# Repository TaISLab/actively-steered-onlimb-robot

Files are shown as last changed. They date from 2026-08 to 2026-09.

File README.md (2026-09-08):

# Actively Steered Open On-Limb Robot 

On-limb robot designed to move along compliant cylindrical surfaces, such as human limbs or pipes. The platform integrates active steering, proprioceptive sensing, embedded control electronics, and compliant mechanical adaptation for locomotion on variable-diameter surfaces.

This repository accompanies the paper:

> Tobar-Subía-Contento, L.M.; Valenzuela, J.; Mandow, A.; Gómez-de-Gabriel, J.M. **"Actively Steered Open On-Limb Robot with Alignment Control and Online Diameter Estimation."** *Electronics* **2026**, *15*(17), 4028. https://doi.org/10.3390/electronics15174028

The main contribution is an integrated open on-limb robotic platform with active steering for real-time locomotion and alignment control. A generalized kinematic framework based on the complete Jacobian of the roller centers provides a geometric alignment variable for closed-loop steering correction and enables coordinate-independent online estimation of the supporting surface diameter from proprioceptive measurements.

Experiments on variable-diameter surfaces demonstrate the robot's ability to maintain centered longitudinal locomotion, handle non-symmetric link deflections, and estimate the local diameter online.

## Repository Contents

The repository is organized into two main sections:

```text
repository/
├── CAD/
├── electronics/
├── ControlSoftware/
├── MICIU+Cofinanciado+AEI.jpg
├── README.md
├── CITATION.cff
└── LICENSE
```

## Mechanical Design

The `mechanical/STL/` directory contains the mechanical components required to fabricate the robot structure using **additive manufacturing (3D printing)**.

The structural components of the prototype reported in the associated publication were fabricated using **polylactic acid (PLA)**.

### 3D Printing

Printing parameters may need to be adjusted depending on the printer, material, nozzle, layer height, and desired mechanical properties.

Users should verify dimensional tolerances and mechanical compatibility before final assembly.

## Electronics

The `electronics/` directory contains the electronic design files associated with the wearable robot prototype.

The electronics were designed using **KiCad** and the directory includes the complete project required to inspect the electrical schematic and PCB layout:

```text
electronics/
├── proyecto_robot_limbot.kicad_pro
├── proyecto_robot_limbot.kicad_sch
└── proyecto_robot_limbot.kicad_pcb
```

The files correspond to:

* **`.kicad_pro`** — KiCad project configuration.
* **`.kicad_sch`** — electronic schematic of the system.
* **`.kicad_pcb`** — printed circuit board (PCB) layout.

The project can be opened directly in **KiCad** using the `.kicad_pro` file.

Temporary files, local configuration files, autosaves, and backup directories generated automatically by KiCad are not included in the repository.

The electronic design files are provided to support reproduction, inspection, and further development of the hardware used in the research prototype.

# Control Software

This folder contains the software used for the control and experimental operation of the actively-steered on-limb robot.

The embedded control code was implemented for the ESP32-based controller and includes motor position control, servo control, sensor acquisition, signal filtering, serial communication, and experimental data transmission.

```text
ControlSoftware/
├── actively-steered-onlimb-robot.ino
├── robot_control_interface.py
```

## Citation

If you use or adapt the files, mechanical designs, or electronic designs contained in this repository for academic or research purposes, please cite the associated publication (see reference above) and, when appropriate, this repository.

GitHub users can use the **“Cite this repository”** option, or refer directly to the `CITATION.cff` file included in this repository, which contains the complete bibliographic metadata for both the article and the repository.

## Funding

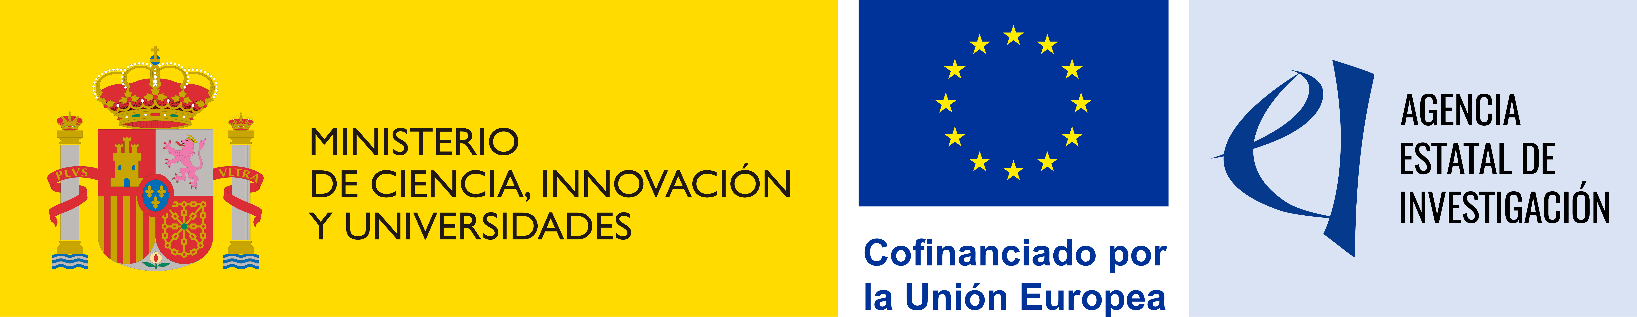
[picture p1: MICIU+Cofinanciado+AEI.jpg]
MICIU/AEI logo


This work is part of project PID2021-127221OB-I00 (CONCERTO — Control Colaborativo para Interacción física Empática entre RoboT y humanO), funded by MICIU/AEI/10.13039/501100011033/FEDER, UE.

## Acknowledgment

This repository accompanies academic research on wearable robotic systems and is provided to facilitate reproducibility and further research in the field.

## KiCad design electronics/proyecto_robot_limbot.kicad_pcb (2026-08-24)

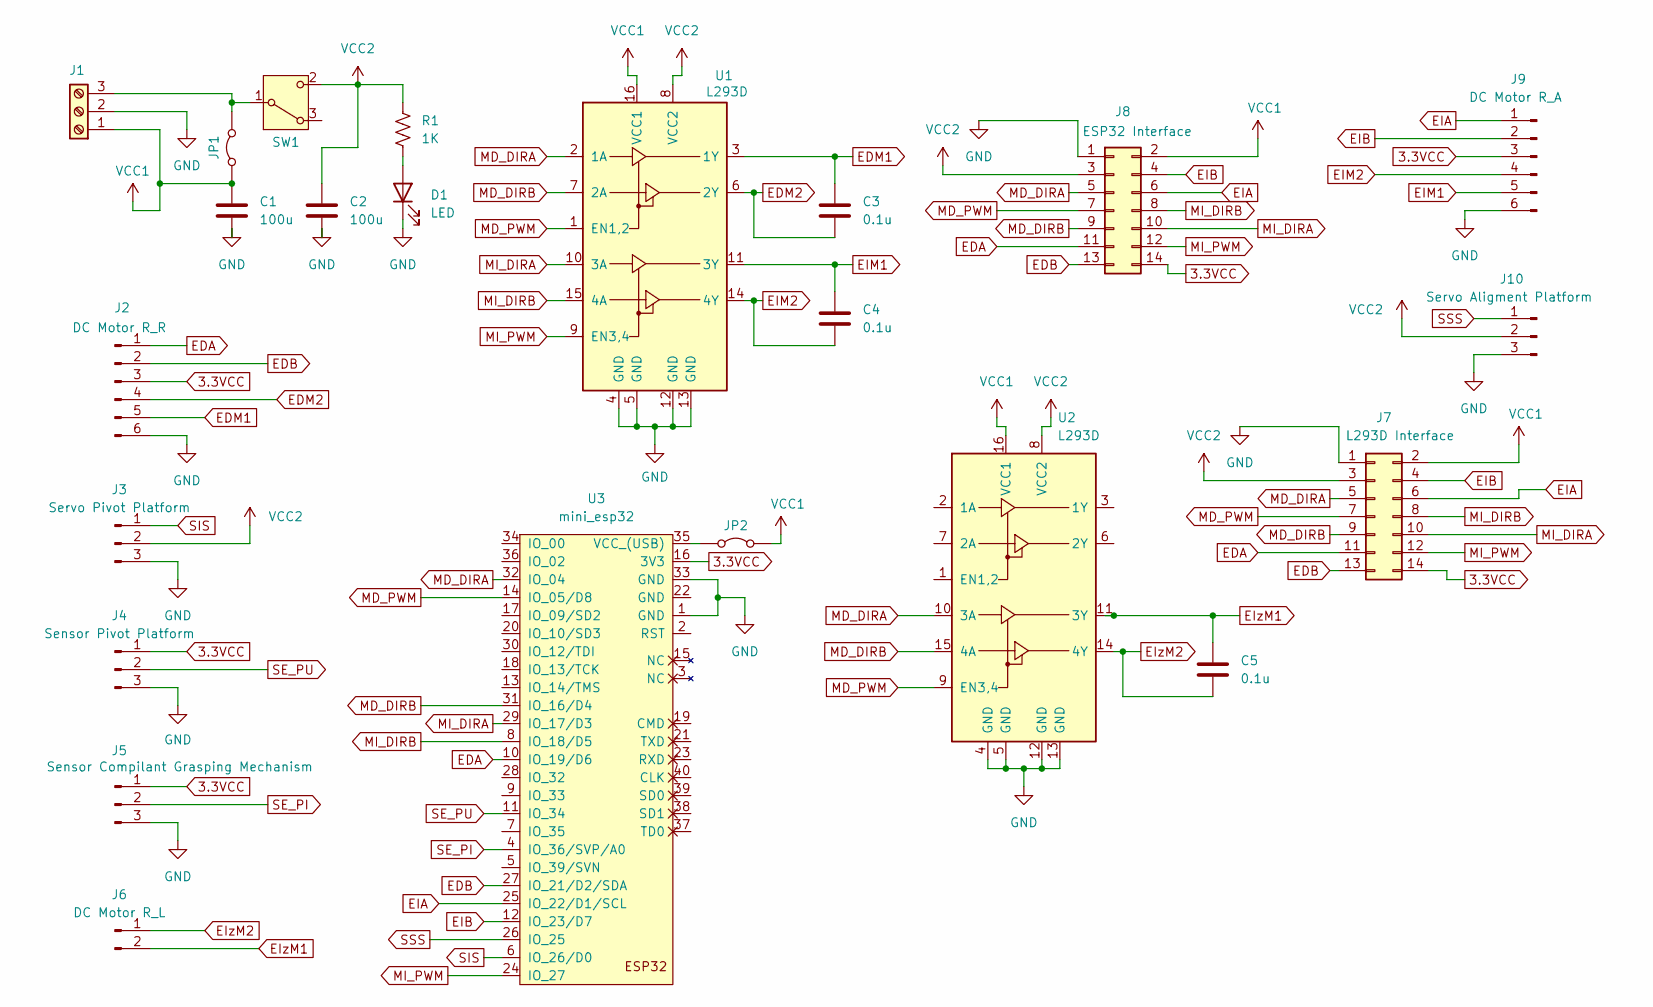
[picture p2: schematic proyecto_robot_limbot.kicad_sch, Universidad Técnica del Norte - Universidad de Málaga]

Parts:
C1, C2: 100u; C_Disc_D3.4mm_W2.1mm_P2.50mm
C3, C4, C5: 0.1u; C_Disc_D3.4mm_W2.1mm_P2.50mm
D1: LED; LED_D3.0mm_Clear
J1: TerminalBlock_MetzConnect_Type086_RT03403HBLC_1x03_P3.81mm_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
J2: DC Motor R_R; Molex_Micro-Latch_53254-0670_1x06_P2.00mm_Horizontal
J3: Servo Pivot Platform; Molex_Micro-Latch_53254-0370_1x03_P2.00mm_Horizontal
J4: Sensor Pivot Platform; Molex_Micro-Latch_53254-0370_1x03_P2.00mm_Horizontal
J5: Sensor Compilant Grasping Mechanism; Molex_Micro-Latch_53254-0370_1x03_P2.00mm_Horizontal
J6: DC Motor R_L; Molex_Micro-Latch_53254-0270_1x02_P2.00mm_Horizontal
J7: L293D Interface; PinSocket_2x07_P2.54mm_Vertical
J8: ESP32 Interface; PinHeader_2x07_P2.54mm_Vertical
J9: DC Motor R_A; Molex_Micro-Latch_53254-0670_1x06_P2.00mm_Horizontal
J10: Servo Aligment Platform; Molex_Micro-Latch_53254-0370_1x03_P2.00mm_Horizontal
JP1, JP2: TestPoint_2Pads_Pitch2.54mm_Drill0.8mm
R1: 1K; R_Axial_DIN0204_L3.6mm_D1.6mm_P5.08mm_Horizontal
SW1: SW_Slide-03_Wuerth-WS-SLTV_10x2.5x6.4_P2.54mm
U1, U2: L293D; DIP-16_W7.62mm_Socket_LongPads
U3: mini_esp32; ESP32_mini

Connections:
3.3VCC: J2.3, J4.1, J5.1, J7.14, J8.14, J9.3, U3.16 (3V3)
EDA: J2.1, J7.11, J8.11, U3.10 (IO_19/D6)
EDB: J2.2, J7.13, J8.13, U3.27 (IO_21/D2/SDA)
EDM1: C3.2, J2.5, U1.3 (1Y)
EDM2: C3.1, J2.4, U1.6 (2Y)
EIA: J7.6, J8.6, J9.1, U3.25 (IO_22/D1/SCL)
EIB: J7.4, J8.4, J9.2, U3.12 (IO_23/D7)
EIM1: C4.1, J9.5, U1.11 (3Y)
EIM2: C4.2, J9.4, U1.14 (4Y)
EIzM1: C5.2, J6.2, U2.11 (3Y)
EIzM2: C5.1, J6.1, U2.14 (4Y)
GND: C1.1, C2.1, D1.1 (K), J1.2, J2.6, J3.3, J4.3, J5.3, J7.1, J8.1, J9.6, J10.3, U1.4 (GND), U1.5 (GND), U1.12 (GND), U1.13 (GND), U2.4 (GND), U2.5 (GND), U2.12 (GND), U2.13 (GND), U3.1 (GND), U3.33 (GND)
MD_DIRA: J7.5, J8.5, U1.2 (1A), U2.10 (3A), U3.32 (IO_04)
MD_DIRB: J7.9, J8.9, U1.7 (2A), U2.15 (4A), U3.31 (IO_16/D4)
MD_PWM: J7.7, J8.7, U1.1 (EN1,2), U2.9 (EN3,4), U3.14 (IO_05/D8)
MI_DIRA: J7.10, J8.10, U1.10 (3A), U3.29 (IO_17/D3)
MI_DIRB: J7.8, J8.8, U1.15 (4A), U3.8 (IO_18/D5)
MI_PWM: J7.12, J8.12, U1.9 (EN3,4), U3.24 (IO_27)
unnamed: D1.2 (A), R1.1
unnamed: J1.3, JP1.2 (B), SW1.1 (B)
unnamed: JP2.1 (A), U3.35 (VCC_(USB))
SE_PI: J5.2, U3.4 (IO_36/SVP/A0)
SE_PU: J4.2, U3.11 (IO_34)
SIS: J3.1, U3.6 (IO_26/D0)
SSS: J10.1, U3.26 (IO_25)
VCC1: C1.2, J1.1, J7.2, J8.2, JP1.1 (A), JP2.2 (B), U1.16 (VCC1), U2.16 (VCC1)
VCC2: C2.2, J3.2, J7.3, J8.3, J10.2, R1.2, SW1.2 (C), U1.8 (VCC2), U2.8 (VCC2)

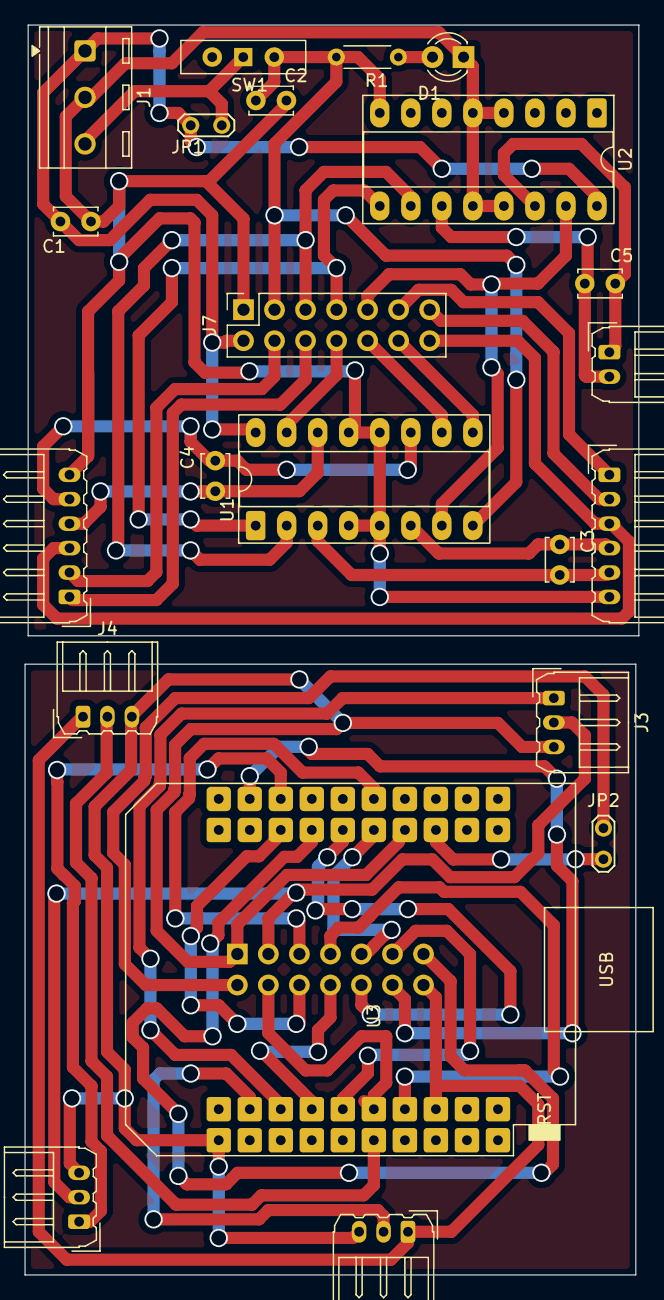
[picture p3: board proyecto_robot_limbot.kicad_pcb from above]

Board: 2 copper layers, 50.3 x 102.3 mm, 23 parts (1 on the bottom side), 27 nets.

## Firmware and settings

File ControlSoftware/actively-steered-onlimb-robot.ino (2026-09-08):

#include <ESP32Encoder.h>
#include <PID_v1.h>
#include <ESP32Servo.h>
/// Placa ESP32 NodeMCU-32s
// ============================
// CONFIGURACIÓN DE PINES
// ============================
#define MD1_DIRA 4      // Motor 1 dirección A
#define MD1_DIRB 16     // Motor 1 dirección B
#define MD1_PWM  5      // Motor 1 PWM
#define E1A 19          // Encoder 1 canal A
#define E1B 21          // Encoder 1 canal B

#define MD2_DIRA 17     // Motor 2 dirección A
#define MD2_DIRB 18     // Motor 2 dirección B
#define MD2_PWM  27     // Motor 2 PWM
#define E2A 22          // Encoder 2 canal A
#define E2B 23          // Encoder 2 canal B

#define SERVO_SSS 26    // Servo SSS
#define SERVO_SIS 25    // Servo SIS
#define SE_PI 36        // Potenciómetro PI (rho)
#define SE_PU 34        // Potenciómetro PU (theta)

long posicionEncoder1 = 0;
long posicionEncoder2 = 0;

// ============================
// OBJETOS Y VARIABLES
// ============================
Servo sss, sis;  // Objetos para servomotores
ESP32Encoder encoderMotor1, encoderMotor2;  // Encoders para motores

// Variables PID para control de posición
double posicionActual1 = 0, salidaPID1 = 0, posicionDeseada1 = 0;
double posicionActual2 = 0, salidaPID2 = 0, posicionDeseada2 = 0;
PID controladorPID1(&posicionActual1, &salidaPID1, &posicionDeseada1, 40.0, 5.0, 0.0, DIRECT);
PID controladorPID2(&posicionActual2, &salidaPID2, &posicionDeseada2, 40.0, 5.0, 0.0, DIRECT);

// Control PI para compensación del servo SIS
double r_input = 0, r_setpoint = 0, r_output = 90;
double Kp_sis = 5, Ki_sis = 0.5;
PID controladorPISIS(&r_input, &r_output, &r_setpoint, Kp_sis, Ki_sis, 0.0, DIRECT);

// Variables para filtro EMA (Exponential Moving Average)
#define ALPHA 0.5        // Factor de suavizado (0.1-0.5)
float filtered_PU = 0, filtered_PI = 0;
bool primera_lectura = true;

// Variables de comunicación con Python
bool enviarDatos = false;      // Controla envío de datos CSV
unsigned long tiempoInicio = 0; // Para timestamp relativo

// Constantes geométricas del brazo robótico
int L1=44, L2=44, L3=93, L4=93;
float betha = radians(13.32); //13.32 ANTERIOR
float Pr[] = {-L1*cos(betha), -L1*sin(betha)};
float Pl[] = {L2*cos(betha), -L2*sin(betha)};

// Tiempos de muestreo
const unsigned long tiempoMuestreo = 10;  // 10ms = 100Hz
const unsigned long tiempoMuestreo2 = 50;  // 50ms = 20Hz
unsigned long tiempoAnterior = 0;

// Relación de transmisión y resolución de encoders
const double relacionTransmision = 298.0 * (27.0 / 21.0);
const int cuentasPorVuelta = 6;
const double cuentasEjeSalida = relacionTransmision * cuentasPorVuelta;

// ============================
// SETUP - Configuración inicial
// ============================
void setup() {
  Serial.begin(115200);    // Inicia comunicación serial
  Serial.setTimeout(10);   // Timeout corto para lectura
  
  // Configurar pines de motores como salidas
  pinMode(MD1_DIRA, OUTPUT); 
  pinMode(MD1_DIRB, OUTPUT); 
  pinMode(MD1_PWM, OUTPUT);
  pinMode(MD2_DIRA, OUTPUT); 
  pinMode(MD2_DIRB, OUTPUT); 
  pinMode(MD2_PWM, OUTPUT);
  
  // Configurar encoders
  encoderMotor1.attachHalfQuad(E1A, E1B);
  encoderMotor2.attachHalfQuad(E2A, E2B);
  encoderMotor1.clearCount();  // Reiniciar contadores
  encoderMotor2.clearCount();
  
  // Configurar controladores PID
  controladorPID1.SetMode(AUTOMATIC);
  controladorPID1.SetOutputLimits(-255, 255);
  controladorPID1.SetSampleTime(tiempoMuestreo);
  
  controladorPID2.SetMode(AUTOMATIC);
  controladorPID2.SetOutputLimits(-255, 255);
  controladorPID2.SetSampleTime(tiempoMuestreo);
  
  // Configurar control PI para servo SIS
  controladorPISIS.SetMode(AUTOMATIC);
  controladorPISIS.SetSampleTime(tiempoMuestreo);
  controladorPISIS.SetOutputLimits(-30, 30); //rango de movimiento del servo inferior
  
  // Configurar servomotores
  sss.attach(SERVO_SSS);
  sis.attach(SERVO_SIS);
  sss.write(90);  // Posición inicial
  sis.write(90);
  
  // Señal de inicio para Python
  Serial.println("ARDUINO_READY");
}

// ============================
// FUNCIÓN: Mover motor
// ============================
void moverMotor(int motor, double velocidad) {
  int dira, dirb, pwmPin;
  
  // Seleccionar pines según motor
  if (motor == 1) { 
    dira = MD1_DIRA; dirb = MD1_DIRB; pwmPin = MD1_PWM; 
  } else { 
    dira = MD2_DIRA; dirb = MD2_DIRB; pwmPin = MD2_PWM; 
  }
  
  // Control de dirección según signo de velocidad
  if (velocidad > 0) { 
    digitalWrite(dira, HIGH); 
    digitalWrite(dirb, LOW); 
  } else if (velocidad < 0) { 
    digitalWrite(dira, LOW); 
    digitalWrite(dirb, HIGH); 
  } else { 
    digitalWrite(dira, LOW); 
    digitalWrite(dirb, LOW); 
  }
  
  // Aplicar PWM (valor absoluto)
  analogWrite(pwmPin, abs((int)velocidad));
}

// ============================
// FUNCIÓN: Leer sensores con filtro EMA
// ============================
void leerSensores(float &rho, float &rho_real, float &theta, float &theta_real) {
  // Leer valores RAW de potenciómetros
  
  float raw_PU = analogRead(SE_PU) - 68.0;  // Theta con comp -6° = Compensación_en_binario = (Compensación_en_grados × 4095) / 360
  float raw_PI = analogRead(SE_PI) - 68.0;  // Rho con comp -6° = Compensación_en_binario = (Compensación_en_grados × 4095) / 360
  
  // Convertir RAW a grados (sin filtro)
  rho_real = (raw_PI * 360.0) / 4095.0;      // Rho real compensado
  theta_real = (raw_PU * 360.0) / 4095.0;    // Theta real compensado
  
  // Aplicar filtro EMA (suavizado exponencial)
  if (primera_lectura) {
    // Primera lectura: inicializar filtros
    filtered_PU = raw_PU;
    filtered_PI = raw_PI;
    primera_lectura = false;
  } else {
    // Aplicar fórmula EMA: nuevo_valor = ALPHA*actual + (1-ALPHA)*anterior
    filtered_PU = ALPHA * raw_PU + (1 - ALPHA) * filtered_PU;
    filtered_PI = ALPHA * raw_PI + (1 - ALPHA) * filtered_PI;
  }
  
  // Convertir valores filtrados a grados
  float val_PU_filt = (filtered_PU * 360.0) / 4095.0;
  float val_PI_filt = (filtered_PI * 360.0) / 4095.0;
  
  theta=val_PU_filt;
  rho=val_PI_filt;


  // Aplicar compensaciones de calibración a valores filtrados
  //theta = 90.0 - fabs(val_PU_filt - 134.0);  // Theta filtrado con compensación
  //rho = val_PI_filt - 99.0;                  // Rho filtrado con compensación
}

// ============================
// FUNCIÓN: Procesar comandos de Python
// ============================
void procesarComandos() {
  if (Serial.available()) {
    String comando = Serial.readStringUntil('\n');
    comando.trim();
    
    // Comando para iniciar/parar envío de datos
    if (comando == "START") {
      enviarDatos = true;
      tiempoInicio = millis();  // Resetear timestamp
      Serial.println("ACK_START");
    }
    else if (comando == "STOP") {
      enviarDatos = false;
      Serial.println("ACK_STOP");
    }
    
    // Comandos de configuración de motores
    else if (comando.startsWith("M1:")) {
      posicionDeseada1 = comando.substring(3).toFloat();
      Serial.print("ACK_M1:");
      Serial.println(posicionDeseada1);
    }
    else if (comando.startsWith("M2:")) {
      posicionDeseada2 = comando.substring(3).toFloat();
      Serial.print("ACK_M2:");
      Serial.println(posicionDeseada2);
    }
    
    // Comandos para servomotores
    else if (comando.startsWith("SSS:")) {
      int angulo = comando.substring(4).toInt();
      sss.write(angulo - 10);  // Compensación de 10 grados
      Serial.print("ACK_SSS:");
      Serial.println(angulo);
    }
    else if (comando.startsWith("SIS:")) {
      int angulo = comando.substring(4).toInt();
      sis.write(angulo);
      Serial.print("ACK_SIS:");
      Serial.println(angulo);
    }
    
    // Solicitar header del CSV
    else if (comando == "HEADER") {
      Serial.println("Timestamp,Pos1,PWM1,Pos2,PWM2,SSS,SIS,rho,rho_real,theta,theta_real,gamma,diametro");
    }
  }
}

// ============================
// FUNCIÓN: Actualizar control PID
// ============================
void actualizarControl() {
  // Leer posiciones actuales de encoders y convertir a grados
  posicionEncoder1 = encoderMotor1.getCount();
  posicionActual1 = (double)posicionEncoder1 * (360.0 / cuentasEjeSalida);
  
  posicionEncoder2 = encoderMotor2.getCount();
  posicionActual2 = (double)posicionEncoder2 * (360.0 / cuentasEjeSalida);
  
  // Calcular salidas PID
  controladorPID1.Compute();
  controladorPID2.Compute();
  
  // Aplicar señales a motores
  moverMotor(1, salidaPID1);
  moverMotor(2, salidaPID2);
}

// ============================
// FUNCIÓN: Calcular r y diámetro del brazo
// ============================
void calcularRDiametro(float &r, float &diametro, float rho_filt, float theta_filt) {
  // L5: distancia entre puntos de unión
  float L5 = sqrt((L4*L4) + (L3*L3) - (2.0 * L4 * L3 * cos(radians(rho_filt))));
  
  // Ángulo tau usando ley de senos
  float tau = asin((sin(radians(rho_filt)) * L4) / L5);
  
  // Ángulo r = theta - tau (convertido a grados)
  r = theta_filt - degrees(tau);
  
  // Coordenadas del punto Pg
  float Pg[2] = { L5 * sin(radians(r)), -L5 * cos(radians(r)) };
  
  // Longitudes de los lados del triángulo
  float L6 = sqrt(pow(Pr[0] - Pg[0], 2) + pow(Pr[1] - Pg[1], 2));
  float L7 = sqrt(pow(Pl[0] - Pr[0], 2) + pow(Pl[1] - Pr[1], 2));
  float L8 = sqrt(pow(Pg[0] - Pl[0], 2) + pow(Pg[1] - Pl[1], 2));
  
  // Área del triángulo usando fórmula de coordenadas
  float A = fabs((Pr[0]*(Pg[1]-Pl[1]) + Pg[0]*(Pl[1]-Pr[1]) + Pl[0]*(Pr[1]-Pg[1])) / 2.0);
  
  // Radio del círculo circunscrito (fórmula geométrica)
  float Rc = ((L6 * L7 * L8) / (4.0 * A)) - 26;  // Restar offset constante
  
  // Diámetro = 2 * radio
  diametro = 2 * Rc;
}

// ============================
// FUNCIÓN: Enviar datos en formato CSV
// ============================
void enviarDatosCSV() {
  if (!enviarDatos) return;  // Solo enviar si está activado
  
  unsigned long tiempo = millis() - tiempoInicio;  // Timestamp relativo
  float rho, rho_real, theta, theta_real, r, diametro;
  
  // Leer sensores (valores reales y filtrados)
  leerSensores(rho, rho_real, theta, theta_real);
  
  // Calcular r y diámetro usando valores FILTRADOS
  calcularRDiametro(r, diametro, rho, theta);
  
  // Control PI para servo SIS usando valor r filtrado
  r_input = r;
  r_setpoint = 0;
  controladorPISIS.Compute();
  sis.write(sss.read() - (float)r_output);  // Compensación
  
  // Enviar línea CSV con todos los datos
  Serial.print(tiempo);                     // Timestamp relativo
  Serial.print(",");
  Serial.print(posicionActual1, 2);         // Posición motor 1
  Serial.print(",");
  Serial.print(salidaPID1, 2);              // PWM motor 1
  Serial.print(",");
  Serial.print(posicionActual2, 2);         // Posición motor 2
  Serial.print(",");
  Serial.print(salidaPID2, 2);              // PWM motor 2
  Serial.print(",");
  Serial.print(sss.read());                 // Ángulo servo SSS
  Serial.print(",");
  Serial.print(sis.read());                 // Ángulo servo SIS
  Serial.print(",");
  Serial.print(rho, 2);                     // Rho FILTRADO (para control)
  Serial.print(",");
  Serial.print(rho_real, 2);                // Rho REAL (para análisis)
  Serial.print(",");
  Serial.print(theta, 2);                   // Theta FILTRADO (para control)
  Serial.print(",");
  Serial.print(theta_real, 2);              // Theta REAL (para análisis)
  Serial.print(",");
  Serial.print(r, 2);                       // Ángulo r (calculado con filtrados)
  Serial.print(",");
  Serial.println(diametro, 2);              // Diámetro (calculado con filtrados)
}

// ============================
// LOOP - Bucle principal
// ============================
void loop() {
  unsigned long t = millis();
  
  // Ejecutar cada tiempoMuestreo (50ms)
  if (t - tiempoAnterior >= tiempoMuestreo2) {
    tiempoAnterior = t;
    
    // 1. Procesar comandos desde Python
    procesarComandos();
    
    // 2. Actualizar control PID de motores
    actualizarControl();
    
    // 3. Enviar datos en formato CSV
    enviarDatosCSV();
  }
}

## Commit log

2026-08-24 Create CAD
2026-09-07 Remove affiliation from README
    Removed the affiliation to TaISLab, Universidad de Málaga.
2026-09-07 Simplify repository contents tree to root-level entries
    Show only the top-level items in the "Repository Contents" tree,
    matching the actual repository structure (CAD/, electronics/, the
    MICIU logo, README.md, CITATION.cff, LICENSE) instead of an outdated
    and partially incorrect nested listing.
    Claude-Session: https://claude.ai/code/session_018UFsP5hdTuumCUHyXZmD6i
